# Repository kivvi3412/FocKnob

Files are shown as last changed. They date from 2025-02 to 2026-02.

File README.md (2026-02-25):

# FOC Smart Knob (基于电机触觉反馈的智能旋钮)

本项目提出并实现了一款基于 FOC（磁场定向控制）无刷电机的智能旋钮。通过实时控制电机的输出力矩，结合圆形屏幕 UI 和 MQTT
物联网通信，在单一旋钮上实现了多种传统机械旋钮的触觉反馈（如阻尼、棘轮、多档吸附等），为智能家居、车载中控等场景提供了一种可高度自定义的高级交互方案。

## 核心特性

* **多模式力反馈**：支持无极旋转、棘轮、多档开关、自适应阻尼及吸附等模式，手感可通过代码参数实时动态调整。
* **闭环控制**：ESP32-S3 主控 + AS5600 磁编码器，通过 SVPWM 算法对无刷电机进行高频精确控制。
* **按压与交互**：内置 HX711 + 压力传感器，支持按压动作识别，实现按压切换菜单等交互。
* **动态 UI 显示**：顶部集成 GC9A01 1.28寸圆形 LCD 屏幕，实时同步当前旋钮状态与物联网设备数据。
* **IoT 互联**：基于 Wi-Fi 和 MQTT 协议，实现低延迟的智能设备联动（如灯光、空调、窗帘等控制）。

## 硬件设计 (Hardware Design)

### 1. 结构与外观

外观采用极简圆柱体设计，内部包含底座、主控板、无刷电机、传动组件及顶部屏幕托盘。

| 外观渲染 | 内部剖面 | 结构爆炸图 |
|:---:|:---:|:---:|
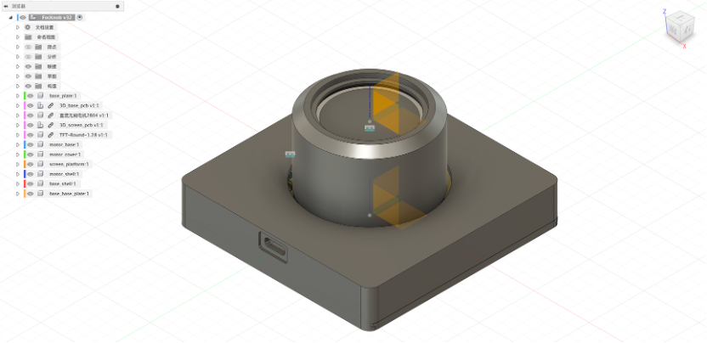
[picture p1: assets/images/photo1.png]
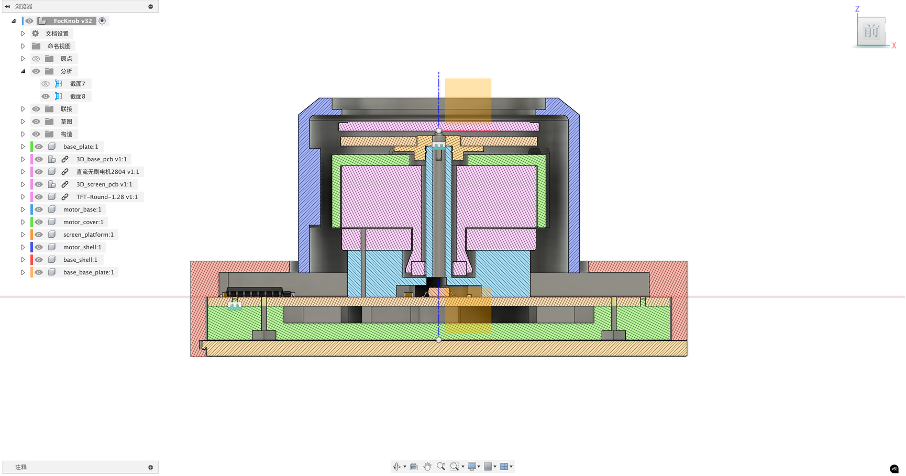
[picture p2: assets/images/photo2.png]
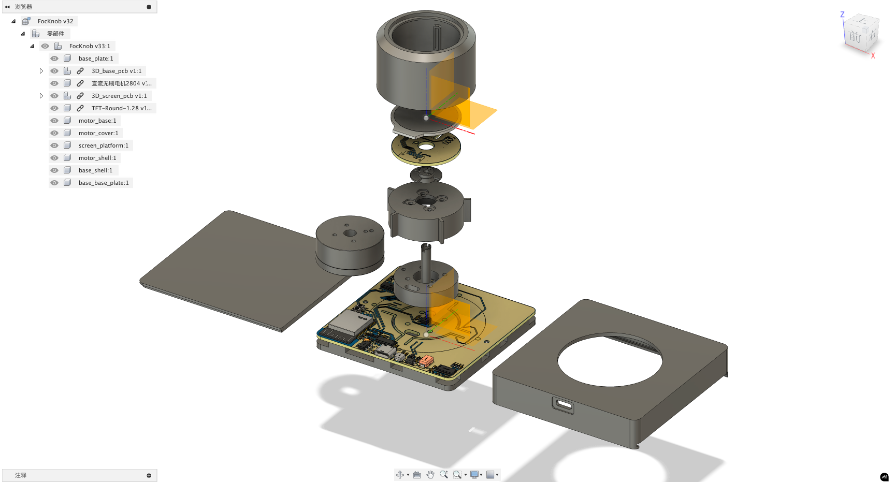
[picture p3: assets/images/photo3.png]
|  |  |  |

### 2. 演示视频

1. 功能演示

     - 演示旋钮在“空调温度”、“灯光亮度”、“窗帘开合”等不同模式下的 UI 联动，以及无极旋转、棘轮、边界回弹等力反馈效果。
       <video src="https://github.com/user-attachments/assets/36b64202-8c5b-4702-a256-0abc116e3df9" width="100%" controls="controls"></video>

2. 产品外观 & 离线运行演示

    <table>
      <tr>
        <th align="center"> 产品演示 (Product Demo)</th>
        <th align="center"> 离线演示 (Offline Demo)</th>
      </tr>
      <tr>
        <td width="50%" align="center">
          <video src="https://github.com/user-attachments/assets/9f6cf707-2e52-49cd-be3b-408049d534c0" width="100%" controls="controls"></video>
        </td>
        <td width="50%" align="center">
          <video src="https://github.com/user-attachments/assets/8a69e512-cf59-46dd-b751-51a924273394" width="100%" controls="controls"></video>
        </td>
      </tr>

    </table>

### 3. PCB 电路设计

包含 3.3V/12V 供电管理、ESP32-S3 最小系统、电机驱动芯片、信号采集及屏幕排线接口。

| 主板 PCB | 屏幕扩展板 PCB |
|:---:|:---:|
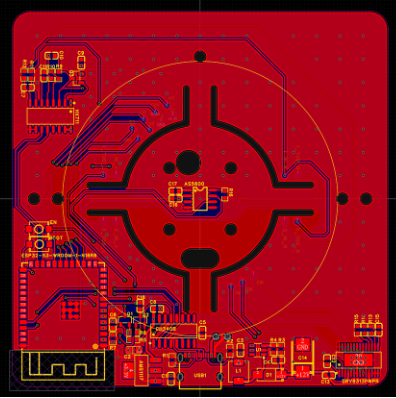
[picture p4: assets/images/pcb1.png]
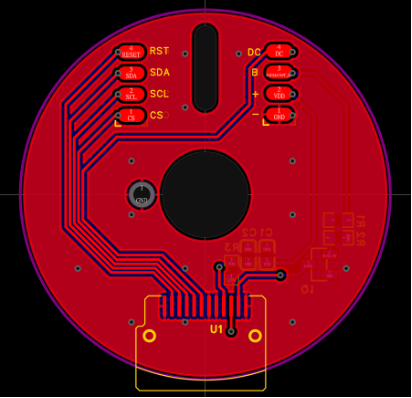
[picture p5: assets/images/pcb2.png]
|  |  |

| 主板 3D 预览 | 屏幕扩展板 3D 预览 |
|:---:|:---:|
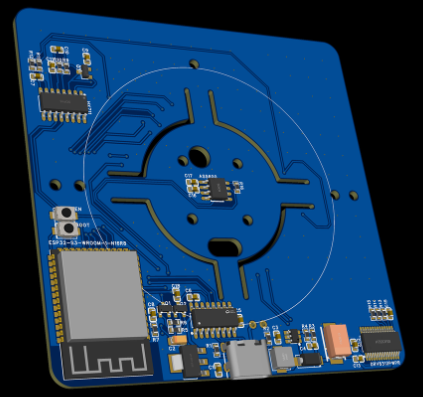
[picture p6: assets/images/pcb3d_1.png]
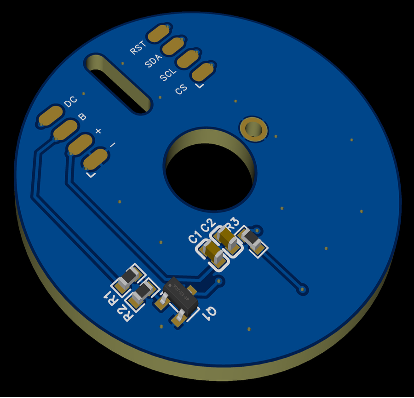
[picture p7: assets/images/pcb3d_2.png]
|  |  |

### 4. 注意事项

- 添加依赖库：
    ```bash
    idf.py add-dependency "lvgl/lvgl^9.2.2"
    idf.py add-dependency "espressif/esp_lcd_gc9a01^2.0.1"
    idf.py add-dependency "espressif/esp_lvgl_port^2.4.4"
    ```
- 需要开启 PSRAM 和 N16R8 需要开启 Octal Mode PSRAM

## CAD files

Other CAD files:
hardware/mechanical/FocKnob v35.f3z
hardware/mechanical/Strain gauge v1.f3d
hardware/mechanical/TFT-Round-1.28 v1.f3d

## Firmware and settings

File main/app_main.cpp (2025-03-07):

#include "freertos/FreeRTOS.h"
#include "freertos/task.h"
#include "esp_log.h"

#include "debug_console.h"
#include "logic_manager.h"
#include "logic_mode.h"
#include "pressure_sensor.h"

void activity_monitor(void *arg) {
    /*
     * @brief 任务统计信息
     *
     * 需要打开以下参数在 idf.py menuconfig 中
     * configTASKLIST_INCLUDE_COREID
     * CONFIG_FREERTOS_GENERATE_RUN_TIME_STATS          // 生成运行时间统计
     * CONFIG_FREERTOS_USE_STATS_FORMATTING_FUNCTIONS   // 使用格式化函数
     * CONFIG_FREERTOS_USE_TRACE_FACILITY               // 使用追踪功能
     */

    // 分配足够大的缓冲区来存储任务统计信息
    char *task_stats_buffer = static_cast<char *>(malloc(4096));
    if (task_stats_buffer == nullptr) {
        printf("无法分配内存来存储任务统计信息\n");
        return;
    }

    while (true) {
        // vTaskList(task_stats_buffer);   // 可以查看任务绑定在哪个CPU上了
        vTaskGetRunTimeStats(task_stats_buffer);    // 可以看CPU占用率
        printf("任务名\t\t运行时间\t\tCPU使用率 (%%) \n");
        printf("%s\n", task_stats_buffer);
        vTaskDelay(pdMS_TO_TICKS(1000));
    }
}

extern "C" void app_main() {
    auto *iic_master = new IICMaster(IIC_MASTER_NUM, IIC_MASTER_SDA_IO, IIC_MASTER_SCL_IO);
    auto *as5600 = new AS5600(iic_master->iic_master_get_bus_handle(), IIC_AS5600_ADDR);
    auto *foc_driver = new FocDriver(FOC_MCPWM_U_GPIO,
                                     FOC_MCPWM_V_GPIO,
                                     FOC_MCPWM_W_GPIO,
                                     FOC_DRV_EN_GPIO,
                                     as5600,
                                     FOC_MOTOR_POLE_PAIRS
    );
    auto *rotary_knob = new RotaryKnob(foc_driver, as5600);
    auto *physical_display = new PhysicalDisplay();
    auto *pressure_sensor = new PressureSensor(HX711_DOUT_GPIO, HX711_SCK_GPIO);
    auto *logic_manager = new LogicManager(pressure_sensor, foc_driver);

    // 设置开机模式
    logic_manager->set_mode(new StartingUpMode(foc_driver, physical_display));

    // 注册模式
    logic_manager->register_mode("UnboundedMode", new UnboundedMode(rotary_knob, physical_display));
    logic_manager->register_mode("BoundedMode", new BoundedMode(rotary_knob, physical_display));
    logic_manager->register_mode("SwitchMode", new SwitchMode(rotary_knob, physical_display));
    logic_manager->register_mode("AttractorMode", new AttractorMode(rotary_knob, physical_display));

    logic_manager->set_mode_by_name("UnboundedMode");

    // xTaskCreatePinnedToCore(activity_monitor, "activity_monitor", 4096, nullptr, 1, nullptr, 1);
}

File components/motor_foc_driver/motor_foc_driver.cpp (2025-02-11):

//
// Created by HAIRONG ZHU on 25-1-14.
//

#include "motor_foc_driver.h"
#include "project_conf.h"
#include "driver/gpio.h"


static const char *TAG = "FocDriver";
#define _constrain(amt, low, high) ((amt)<(low)?(low):((amt)>(high)?(high):(amt)))


FocDriver::FocDriver(gpio_num_t u_gpio,
                     gpio_num_t v_gpio,
                     gpio_num_t w_gpio,
                     gpio_num_t en_gpio,
                     AS5600 *as5600,
                     int pole_pairs) : en_gpio_(en_gpio),
                                       as5600_(as5600),
                                       pole_pairs_(pole_pairs) {
    // 初始化电机驱动，使能引脚, 创建逆变器
    inverter_config_t cfg = {
            .timer_config = {
                    .group_id = 0,
                    .clk_src = MCPWM_TIMER_CLK_SRC_DEFAULT,
                    .resolution_hz = FOC_MCPWM_TIMER_RESOLUTION_HZ,
                    .count_mode = MCPWM_TIMER_COUNT_MODE_UP_DOWN,
                    .period_ticks = FOC_MCPWM_PERIOD,
            },
            .operator_config = {
                    .group_id = 0,
            },
            .compare_config = {
                    .flags = {
                            .update_cmp_on_tez = true,
                    },
            },
            .gen_gpios = {
                    u_gpio,
                    v_gpio,
                    w_gpio,
            },
    };

    ESP_ERROR_CHECK(svpwm_new_inverter(&cfg, &inverter_));   // 新建一个逆变器
    ESP_ERROR_CHECK(svpwm_inverter_start(inverter_, MCPWM_TIMER_START_NO_STOP)); // 启动逆变器
    ESP_LOGI(TAG, "Inverter init OK");

    gpio_config_t drv_en_config = {
            .pin_bit_mask = 1ULL << en_gpio,
            .mode = GPIO_MODE_OUTPUT,
    };
    ESP_ERROR_CHECK(gpio_config(&drv_en_config));

    // 创建FOC计算任务
//    xTaskCreate(_foc_task_static, "foc_calc_task", 4096, this, configMAX_PRIORITIES - 1, &foc_task_handle_);
    xTaskCreatePinnedToCore(
            _foc_task_static,
            "foc_calc_task",
            4096,
            this,
            20, //configMAX_PRIORITIES - 1
            &foc_task_handle_,
            0
    );

    // 创建 foc 主循环定时器
    // 开启 menuconfig 的 CONFIG_ESP_TIMER_SUPPORTS_ISR_DISPATCH_METHOD, .dispatch_method = ESP_TIMER_ISR,
    // 调整优先级 组件配置 → ESP Timer → Timer task priority
    const esp_timer_create_args_t timer_args = {
            .callback = &_timer_callback_static,
            .arg = this,
            .name = "foc_loop_timer"
    };

    ESP_ERROR_CHECK(esp_timer_create(&timer_args, &foc_timer));
    ESP_ERROR_CHECK(esp_timer_start_periodic(foc_timer, FOC_CALC_PERIOD));
}

void FocDriver::bsp_bridge_driver_enable(bool enable) {
    foc_is_enabled_ = enable;
    ESP_LOGI(TAG, "%s MOSFET gate", foc_is_enabled_ ? "Enable" : "Disable");
    gpio_set_level((gpio_num_t) en_gpio_, foc_is_enabled_);
}

/**
 * @brief 电机自检函数：开环正转，检测编码器读数变化方向，设置零电角度
 */
void FocDriver::foc_motor_calibrate() {
    if (!foc_is_enabled_) {
        ESP_LOGW(TAG, "Please enable the motor driver first");
        return;
    }
    // 关闭主循环
    esp_timer_stop(foc_timer);

    // 第一步: 确定电机的旋转方向
    ESP_LOGI(TAG, "Starting motor direction calibration...");
    float theta = 0;
    float delta_theta = M_TWOPI * 0.01;  // 每次的角度增量
    int test_steps = 30;

    // 施加初始电压并等待稳定
    _set_dq_out_exec(0, FOC_MCPWM_CALIBRATE_VOLTAGE, 0);  // 开环运行电机到0度
    vTaskDelay(pdMS_TO_TICKS(300));  // 延时300ms
    float initial_angle = as5600_->read_radian_from_sensor_with_no_update();  // 读取编码器角度

    for (int i = 0; i < test_steps; i++) {
        theta += delta_theta;
        _set_dq_out_exec(0, FOC_MCPWM_CALIBRATE_VOLTAGE, theta);
        vTaskDelay(pdMS_TO_TICKS(10));
    }

    float final_angle = as5600_->read_radian_from_sensor_with_no_update();  // 读取最终角度

    // 停止电机
    _set_dq_out_exec(0, 0, theta);
    float angle_difference = final_angle - initial_angle;   // 计算角度差
    if (angle_difference < -M_PI) { // 角度差归一化
        angle_difference += 2 * M_PI;
    } else if (angle_difference > M_PI) {
        angle_difference -= 2 * M_PI;
    }

    // 判断电机旋转方向
    as5600_direction_ = (angle_difference > 0) ? 1.0f : -1.0f;
    ESP_LOGI(TAG, "Motor direction is %s", (as5600_direction_ > 0) ? "1" : "-1");
    // 设置零电角度
    /*
     * @brief 如果设置 Q 的话是不是代表超前 90 度就不是 0 电位角了, 所以需要设置 D 轴 (犯的经典错误(整整搞了一整天!!))
     *        如果不进行零位校准, 就会发生什么 ?
     *        定子磁场与转子磁场不同步: 控制算法认为转子在零位置, 但实际可能在其他位置。这导致定子产生的磁场与转子磁场之间存在相位差。
     *        扭矩产生效率低: 由于相位差, 产生的扭矩不是最大化的, 需要更多的电流来产生相同的扭矩, 导致功率损耗增加。
     *        运行不稳定: 可能出现震荡 、 抖动 、 噪音等问题。
     *        https://www.bilibili.com/video/BV1Bfq6YLEZ2
     */

    // 第二步: 设置零电角度
    vTaskDelay(pdMS_TO_TICKS(500));
    ESP_LOGI(TAG, "Setting zero electrical angle...");

    // 施加D轴电压, 使电机定子磁场对准零位
    _set_dq_out_exec(FOC_MCPWM_CALIBRATE_VOLTAGE, 0, 0);
    vTaskDelay(pdMS_TO_TICKS(1000));

    // 读取编码器角度, 计算零电角度
    zero_electric_angle_ = as5600_->read_radian_from_sensor_with_no_update() * (float) pole_pairs_ * as5600_direction_;
    vTaskDelay(pdMS_TO_TICKS(100));

    // 停止电机
    _set_dq_out_exec(0, 0, 0);
    ESP_LOGI(TAG, "Zero electrical angle is set to %.2f rad", zero_electric_angle_);
    ESP_LOGI(TAG, "Motor direction calibration done.");

    // 重新启动主循环
    esp_timer_start_periodic(foc_timer, FOC_CALC_PERIOD);
}

void FocDriver::set_free() {
    current_mode_ = Mode::None;
}

void FocDriver::set_dq(float Ud, float Uq) {
    current_uq_ = Uq;
    current_ud_ = Ud;
    current_mode_ = Mode::TorqueControl;
}

void FocDriver::set_velocity(float speed_rad_s, PIDController *pid_velocity) {
    target_speed_rad_s_ = speed_rad_s;
    pid_velocity_ = pid_velocity;
    current_mode_ = Mode::VelocityControl;
}

void FocDriver::set_abs_position(float position_rad, PIDController *pid_position, PIDController *pid_position_v) {
    target_position_rad_ = position_rad;
    pid_position_ = pid_position;
    pid_position_velocity_ = pid_position_v;
    current_mode_ = Mode::AbsPositionControl;
}

void FocDriver::set_rel_position(float position_rad, PIDController *pid_position, PIDController *pid_position_v) {
    target_position_rad_ = position_rad;
    pid_position_ = pid_position;
    pid_position_velocity_ = pid_position_v;
    current_mode_ = Mode::RelPositionControl;
}


// private
float FocDriver::_normalize_angle(float angle) {
    float a = fmodf(angle, 2.0f * M_PI);   //取余运算可以用于归一化，列出特殊值例子算便知
    return a >= 0 ? a : (a + 2.0f * (float) M_PI);
}

float FocDriver::_get_electrical_angle() {
    return as5600_->read_radian_from_sensor() * (float) pole_pairs_ * as5600_direction_ - zero_electric_angle_;
}

void FocDriver::_timer_callback_static(void *args) {
    auto *self = static_cast<FocDriver *>(args);
    BaseType_t xHigherPriorityTaskWoken = pdFALSE;
    vTaskNotifyGiveFromISR(self->foc_task_handle_, &xHigherPriorityTaskWoken);  // 通知FOC任务
    portYIELD_FROM_ISR();
}

void FocDriver::_foc_task_static(void *arg) {
    auto *self = static_cast<FocDriver *>(arg);
    self->_set_dq_out_loop();
}
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

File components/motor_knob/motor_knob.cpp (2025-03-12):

#include "motor_knob.h"
#include "project_conf.h" // 包含项目配置, 例如 FOC_CALC_PERIOD

#include <cmath>

#define _constrain(amt, low, high) ((amt)<(low)?(low):((amt)>(high)?(high):(amt)))

RotaryKnob::RotaryKnob(FocDriver *focDriver, AS5600 *as5600)
    : foc_driver_(focDriver), as5600_(as5600) {
    const esp_timer_create_args_t timer_args = {
        .callback = &RotaryKnob::_timer_callback_static,
        .arg = this,
        .name = "rotary_knob_timer"
    };
    ESP_ERROR_CHECK(esp_timer_create(&timer_args, &knob_timer_));
    ESP_ERROR_CHECK(esp_timer_start_periodic(knob_timer_, FOC_CALC_PERIOD));
}

void RotaryKnob::stop() {
    current_mode_ = Mode::None;
    foc_driver_->set_dq(0, 0);
}

// 如果不重置，使用current_radian
void RotaryKnob::attractor(int attractor_num, bool reset_custom_pos, float current_radian) {
    attractor_number_ = (attractor_num < 1) ? 1 : attractor_num;
    if (reset_custom_pos) {
        as5600_->reset_custom_total_radian(); // 重置自定义总弧度
    } else {
        as5600_->set_custom_total_radian(current_radian);
    }
    current_mode_ = Mode::Attractor;
}

/*
 * @brief 设置棘轮吸附模式，超出边界后反弹, 当前角度为0度，指向left_rad, 顺时针旋转pos增大，如果 a_num = 2 则有吸附点 0 和 1
 */
void RotaryKnob::attractor_with_rebound(int attractor_num, float left_rad, float right_rad, bool reset_custom_pos,
                                        float current_radian) {
    attractor_number_ = (attractor_num < 1) ? 1 : attractor_num - 1;
    left_boundary_rad_ = left_rad;
    right_boundary_rad_ = right_rad;

    if (reset_custom_pos) {
        as5600_->set_custom_total_radian(left_rad); // 重置自定义总弧度
    } else {
        as5600_->set_custom_total_radian(current_radian);
    }
    current_mode_ = Mode::AttractorWithRebound;
}

void RotaryKnob::damping(float damping_gain, bool reset_custom_pos, float current_radian) {
    damping_gain_ = damping_gain;

    if (reset_custom_pos) {
        as5600_->reset_custom_total_radian(); // 重置自定义总弧度
    } else {
        as5600_->set_custom_total_radian(current_radian);
    }
    current_mode_ = Mode::Damping;
}

void RotaryKnob::damping_with_rebound(float damping_gain, float left_rad, float right_rad, bool reset_custom_pos,
                                      float current_radian) {
    damping_gain_ = damping_gain;
    left_boundary_rad_ = left_rad;
    right_boundary_rad_ = right_rad;

    if (reset_custom_pos) {
        as5600_->set_custom_total_radian(left_rad); // 重置自定义总弧度
    } else {
        as5600_->set_custom_total_radian(current_radian);
    }
    current_mode_ = Mode::DampingWithRebound;
}

int RotaryKnob::attractor_get_pos() const {
    return attractor_current_pos_;
}

float RotaryKnob::damping_get_pos() const {
    return damping_current_pos_;
}

float RotaryKnob::get_current_radian() const {
    return as5600_->get_custom_total_radian();
}


// private
void RotaryKnob::_timer_callback_static(void *args) {
    auto *self = static_cast<RotaryKnob *>(args);
    self->_knob_loop();
}

void RotaryKnob::_knob_loop() {
    float current_rad = as5600_->get_custom_total_radian();

    switch (current_mode_) {
        case Mode::Attractor: {
            // 棘轮吸附模式
            // 计算一个简单的kp, 并做饱和处理
            float kp = 100.0f * logf((float) attractor_number_ + 1.0f) + 100.0f;
            if (kp > 1000.0f) kp = 1000.0f; // 饱和上限

            float attractor_distance = float(M_TWOPI) / float(attractor_number_);
            // 找到最近的吸附点(可简单用 round())
            float target = std::round(current_rad / attractor_distance) * attractor_distance;
            // 更新当前吸附点
            attractor_current_pos_ = int(target / attractor_distance);
            float error = target - current_rad;

            // 设置力矩： dq_out(0, kp*error)
            float Uq = _constrain(kp * error, -FOC_MCPWM_OUTPUT_LIMIT / 3.0f, FOC_MCPWM_OUTPUT_LIMIT / 3.0f);
            foc_driver_->set_dq(0, Uq);
            break;
        }
        case Mode::AttractorWithRebound: {
            // 棘轮吸附模式，超出边界后反弹
            // 计算吸附位置
            float range_rad = right_boundary_rad_ - left_boundary_rad_;
            float attractor_distance = range_rad / float(attractor_number_);
            int attractor_index = static_cast<int>(roundf((current_rad - left_boundary_rad_) / attractor_distance));
            // 限制吸附点索引
            attractor_index = _constrain(attractor_index, 0, attractor_number_);
            // 计算目标位置
            float target_rad = left_boundary_rad_ + float(attractor_index) * attractor_distance;
            // 更新当前吸附位置
            attractor_current_pos_ = attractor_index;
            // 计算误差和控制力矩
            float error = target_rad - current_rad;
            float kp = 150.0f;
            float torque = _constrain(kp * error, -FOC_MCPWM_OUTPUT_LIMIT / 3.0f, FOC_MCPWM_OUTPUT_LIMIT / 3.0f);
            foc_driver_->set_dq(0, torque);
            break;
        }
        case Mode::Damping: {
            damping_current_pos_ = current_rad;
            float velocity = as5600_->get_velocity_filter();
            if (std::fabs(velocity) < 0.1f) {
                velocity = 0.0f;
            }
            float torque = -damping_gain_ * velocity;
            torque = _constrain(torque, -FOC_MCPWM_OUTPUT_LIMIT / 3.0f, FOC_MCPWM_OUTPUT_LIMIT / 3.0f);
            foc_driver_->set_dq(0, torque);
            break;
        }
        case Mode::DampingWithRebound: {
            if (current_rad < left_boundary_rad_ || current_rad > right_boundary_rad_) {
                float error = 0.0f;
                if (current_rad < left_boundary_rad_) {
                    error = left_boundary_rad_ - current_rad;
                } else if (current_rad > right_boundary_rad_) {
                    error = right_boundary_rad_ - current_rad;
                }
                float kp = 150.0f; // 自行调参
                float torque = _constrain(kp * error, -FOC_MCPWM_OUTPUT_LIMIT / 3.0f, FOC_MCPWM_OUTPUT_LIMIT / 3.0f);
                foc_driver_->set_dq(0, torque);
            } else {
                damping_current_pos_ = current_rad;
                float velocity = as5600_->get_velocity_filter();
                if (std::fabs(velocity) < 0.1f) {
                    velocity = 0.0f;
                }
                float torque = -damping_gain_ * velocity;
                torque = _constrain(torque, -FOC_MCPWM_OUTPUT_LIMIT / 3.0f, FOC_MCPWM_OUTPUT_LIMIT / 3.0f);
                foc_driver_->set_dq(0, torque);
            }
            break;
        }
        case Mode::None: {
            break;
        }
    }
}

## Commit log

2025-01-15 feat: 添加电机 FOC 驱动及相关模块 - 新增 motor_foc_driver 组件, 实现 SVPWM 逆变器 、 FOC 算法及电机控制主循环 - 新增 iic_master 模块, 封装 I2C 主机初始化逻辑 - 新增 iic_as5600 模块, 封装 AS5600 磁编码器的读取和处理 - 新增 debug_console 模块, 添加调试命令行接口, 支持参数设置和状态查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
2025-02-06 feat: 完成 FOC_Driver 的编写 - 完成力矩，位置，速度环 - PID 控制器
2025-02-07 feat: 完成了 RotaryKnob 的编写，增加四种模式 - 棘轮吸附模式 - 棘轮吸附模式，超出边界后反弹 - 阻尼模式 - 阻尼模式，超出边界后反弹
2025-02-10 feat: 完成了演示表盘的编写 - 完成了 knob 的基本功能 - 可以电机反馈 + 屏幕显示反馈
2025-02-11 feat: 软件功能基本完成，电机和屏幕可以配合正常，力反馈正常，足够演示使用
2025-02-16 增加了压力反馈，临时存档
2025-02-16 临时存档2
2025-02-16 feat: 包含压力传感器的基本功能完成 - 增加压力传感器的力反馈
2025-03-07 refactor: 修复了屏幕显示问题，压力传感器问题，内存释放问题
2026-02-25 docs: 更新README.md
    [FocKnob v35.f3z, Strain gauge v1.f3d, TFT-Round-1.28 v1.f3d]
